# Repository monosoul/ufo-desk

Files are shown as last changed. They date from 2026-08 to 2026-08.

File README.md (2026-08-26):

This is an ESPHome component for controlling a lifting desk of an unknown model.
======
Upd: It was noticed that a very similar model has been marketed as KLIFT SBASE by a French company KQueo (Only in France?)

[KLIFT SBASE Manual](pic/klift_sbase.pdf)

Thanks [@ryan-feeley](https://github.com/ryan-feeley) 

Story
======
Some time ago I picked up a used frame of a lifting desk with broken electronics. Quick research revealed that it didn't seem to be any of the known models that you can read about here for example https://community.home-assistant.io/t/desky-standing-desk-esphome-works-with-desky-uplift-jiecang-assmann-others/383790 

The problem was the the control panel didn't turn on every time. In fact, you had to plug and unplug it a hundred times
for it to finally come alive. Physically it seemed ok and I didn't have enough expertise in electronics to investigate
it further, so I connected a logic analyzer, managed to turn it on and recorded some bytes that I later used to put
this component together. I've also sketched a case that can be 3D printed.

[Some pictures of it](pic/pics.md)

Final product
======
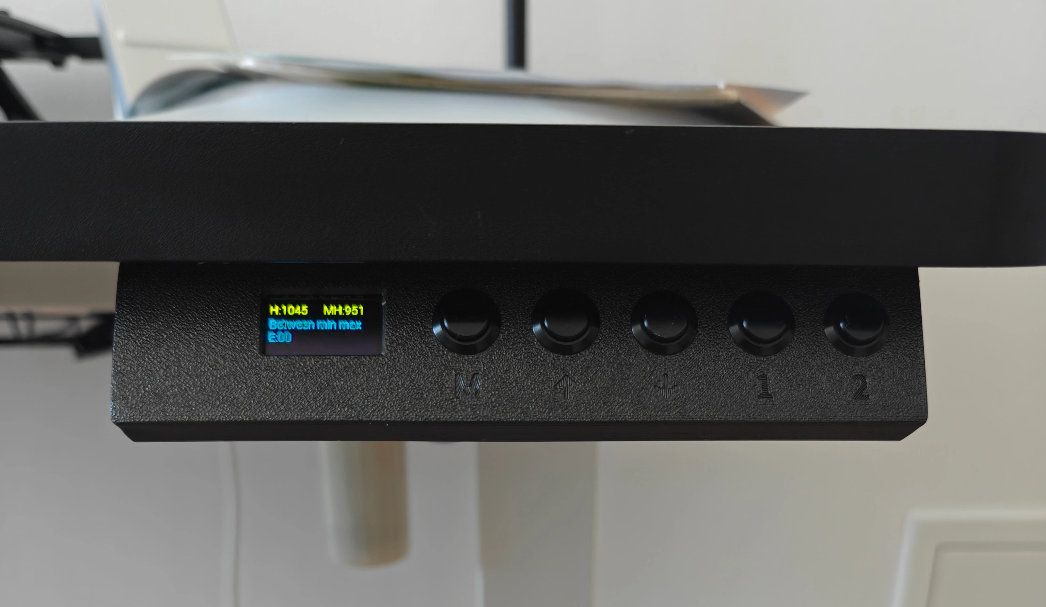
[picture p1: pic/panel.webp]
Looks like this


Hardware
======
The component assumes that you use it with a popular ESP8266 NodeMCU module with a 0.96 inch display that looks like this:

NodeMCU

Case is 3D printed.

The board: https://amzn.eu/d/06bsWsrh / https://de.aliexpress.com/item/1005005242283189.html

The buttons: https://amzn.eu/d/0ePJtrS1 (or any other 12 mm push buttons)

### Control box hardware mods
In my case the Control Box was making high-pitched whine with the board attached (see example here: https://youtube.com/shorts/FGPJeh3KBNg ).

To alleviate that I applied a silicon sealant (this one: https://amzn.eu/d/05OSW01C ) to the capacitor at E2 (the noisiest one), then C14 and MOV2 (those were the next noisiest ones), and then applied it to other coiled elements, just in case.
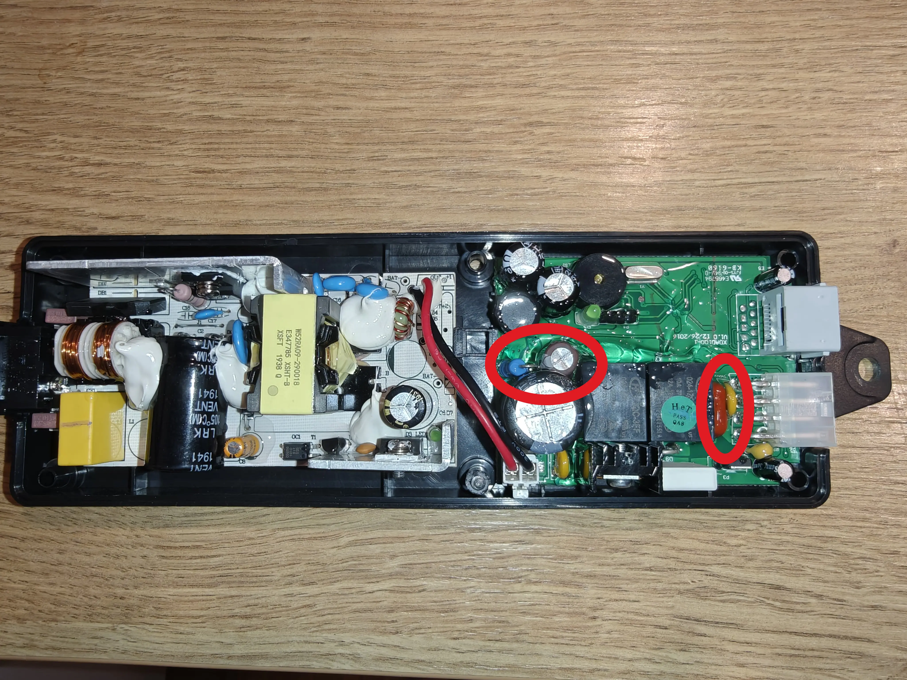
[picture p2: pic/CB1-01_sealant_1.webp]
CB1-01-sealant-1


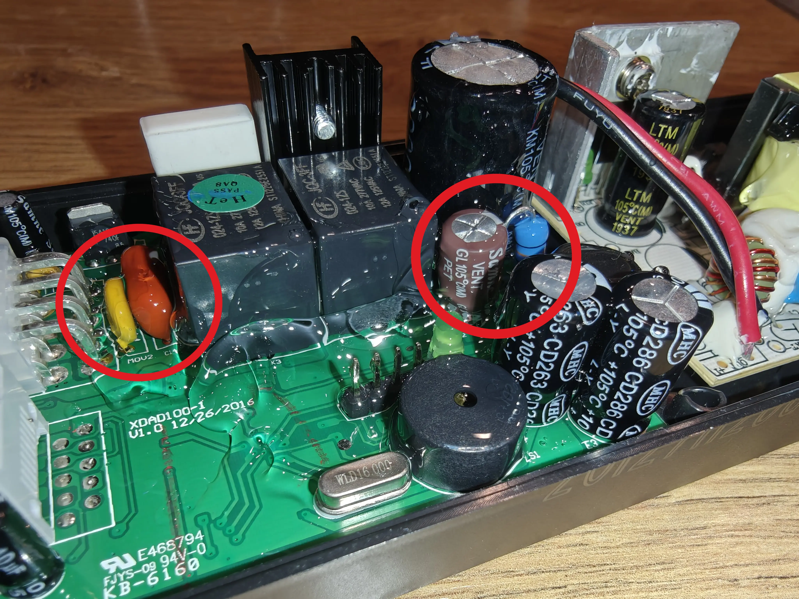
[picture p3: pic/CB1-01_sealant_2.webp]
CB1-01-sealant-2


### RJ-45 wiring is as follows
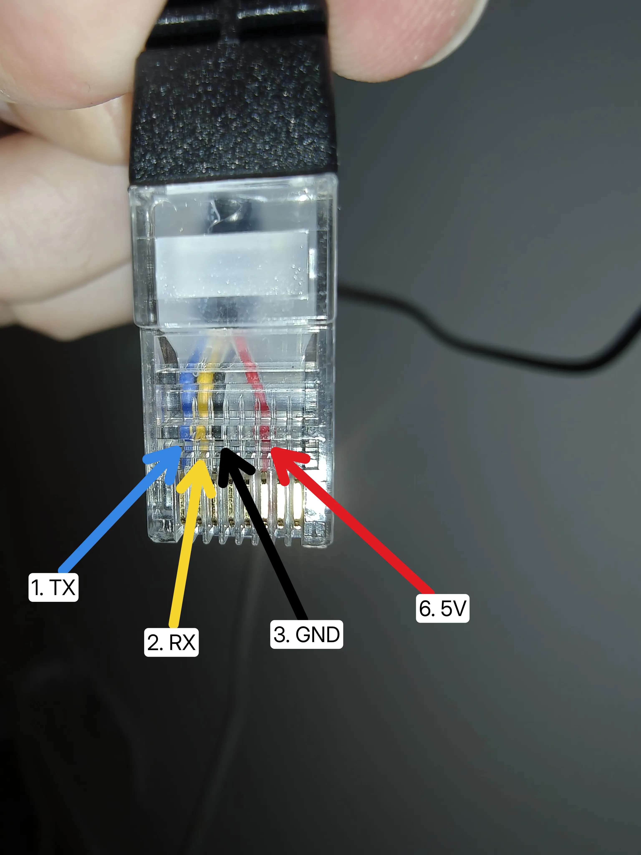
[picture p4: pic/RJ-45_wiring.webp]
Wiring


Case
======
[STL file](cad/ufo_desk_case.stl)

Model is here: 
https://cad.onshape.com/documents/fb08a78e39c84b65334fa29c/w/a40ad3b786aaea1566da89c6/e/d2752561d687634f210bc781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

Home Assistant
======
Since Home Assistant support is basically free in ESPHome I've exposed a couple of things just to 
give it a try. There is more that can be done, but I don't actually use it, so maybe later.

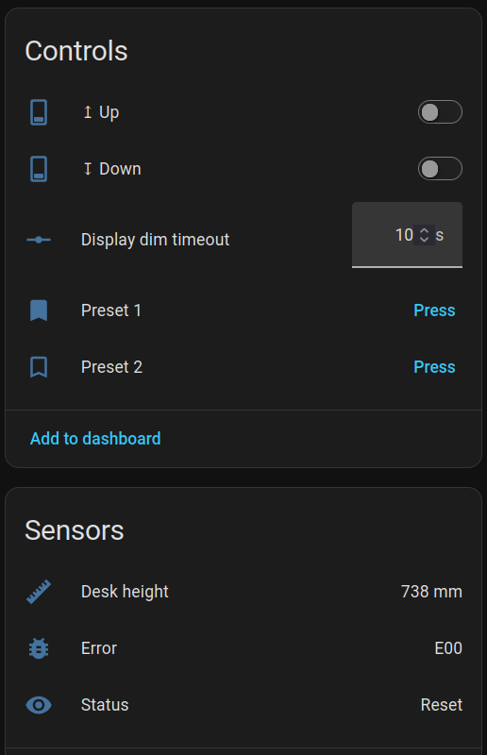
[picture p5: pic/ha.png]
HA


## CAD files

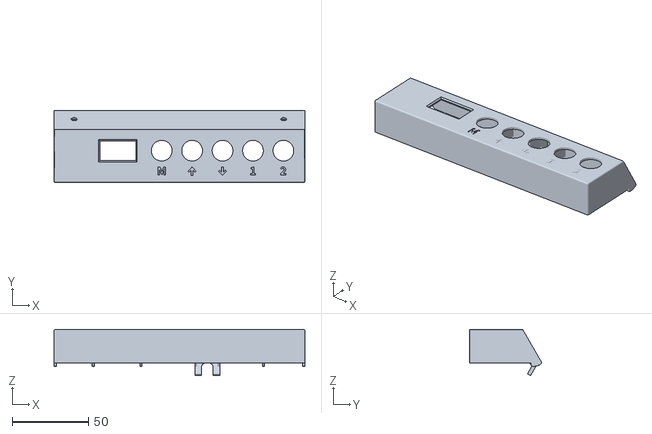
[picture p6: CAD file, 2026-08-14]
cad/ufo_desk_case.stl
165.0 x 47.5 x 30.5

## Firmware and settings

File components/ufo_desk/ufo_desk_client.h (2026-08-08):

#pragma once

#include <cstdint>
#include <array>
#include <string>
#include <functional>

namespace esphome::ufo_desk {

enum class UfoDeskEventType : int {
  curHeightChanged = 0,
  storedHeightChanged,
  errorChanged,
  positionStatusChanged,
  btnStateChanged,
  programmingModeChanged,
};

enum class Button : int {
  none,
  mem,
  up,
  down,
  preset1,
  preset2,
  calibrate,
};

enum class PositionStatus : int {
  unknown = 0,
  maxOut,
  bottomOut,
  betweenMinMax,
  movingSlow,
  movingFast,
  reset,
  resetting,
};

class UfoDeskClient;
struct UfoDeskEvent {
  UfoDeskEvent(UfoDeskEventType type_, UfoDeskClient &desk_) : type(type_), desk(desk_) {}
  UfoDeskEventType type;
  UfoDeskClient &desk;
};

class UfoDeskClient {
 public:
  static constexpr unsigned int kResponseSize = 14;

  using UfoDeskEventHandler = std::function<void(UfoDeskEvent)>;

  void push_button(Button b);
  void release_button();
  Button pushed_button() const;

  int cur_height_mm() const;
  int stored_height_mm() const;
  int error_code() const;
  bool programming_mode() const;
  PositionStatus position_status() const;
  const std::string &position_status_str() const;

  const uint8_t *request_buf() const;
  unsigned int request_buf_size() const;

  bool parse_response(const std::array<uint8_t, kResponseSize> &resp_buf);

  void set_event_handler(UfoDeskEventHandler &&handler);

  static uint16_t crc16_modbus(const unsigned char *buf, unsigned int len);
  static const std::string &pos_status_to_str(PositionStatus s);

 private:
  void update_request_checksum();
  void publish_event(UfoDeskEventType event_type);

  int cur_height_mm_ = 0;
  int stored_height_mm_ = 0;
  int error_code_ = -1;
  bool programming_mode_ = false;
  PositionStatus position_status_ = PositionStatus::unknown;
  Button pushed_button_ = Button::none;

  UfoDeskEventHandler event_handler_;

  std::array<uint8_t, 8> request_buf_ = {0xea, 0xf5, 0x22, 0x00, 0x00, 0x22, 0x8a, 0x45};
};

}  // namespace esphome::ufo_desk

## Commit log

2026-08-06 Add screen auto-dim (interval + activity timestamp) (#1)
    Non-blocking display timeout: activity handlers only stamp a
    timestamp; a 1s interval toggles the panel off/on and only calls
    turn_off()/turn_on() on the actual state transition, so it never
    storms I2C from the high-frequency on_desk_event. Timeout is
    runtime-configurable via a template number exposed to HA.
2026-08-06 Add RJ-45 wiring info
2026-08-07 Add board and buttons links
2026-08-08 feat: programming mode set (#2)
    * Show "SET" on OLED while box is in memory-programming mode
    Decode bit0 of response byte 2 (0x01 while the M button is held and the
    control box is armed to store a preset) as a programming_mode flag, and
    fire a programmingModeChanged event. The display shows a static "SET"
    while the flag is active, restoring the feedback the stock panel gave by
    flashing its own display. Reverse-engineered via logic-analyzer capture.
2026-08-08 feat: hold updown calibrate (#3)
    * Add hold-UP+DOWN calibration (replicating the stock remote)
    Calibration (both columns home to the bottom) is a dedicated request
    code 0x88, streamed while held. Add Button::calibrate, give the up/down
    gpio buttons ids, and coordinate them: both held stays still, arms after
    10s of continuous hold, then streams 0x88; releasing either stops it and
    resumes the remaining single-button direction. Physical buttons only.
2026-08-08 Expose desk presets to Home Assistant as buttons (#4)
    Add template button entities Preset 1 / Preset 2 that recall the desk's
    stored heights. Each press briefly holds the preset code (300ms, ensuring
    at least one 200ms UART poll transmits it) then releases, mirroring a
    physical tap which latches the desk's auto-move. Recall only.
2026-08-14 update cad and pics
    [ufo_desk_case.stl]
2026-08-14 Can't use D8 for buttons
